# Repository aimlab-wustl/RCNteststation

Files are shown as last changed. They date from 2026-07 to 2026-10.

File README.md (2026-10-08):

# Automated Analog and Neuromorphic Integrated Circuits Test-Station

Characterizing a fabricated analog or neuromorphic IC often requires several instruments, separate software interfaces, and repeated manual setup for each device. This makes measurements slow to run and difficult to reproduce. The test station brings programmable biasing, precision voltage and current measurement, fast transient capture, and Python control into one modular system so that researchers can reuse the hardware and compare results across devices.

This project is supported in part by a Research Coordination Network (RCN) grant from the National Science Foundation (NSF), grant no. **2332166**.

[System documentation](https://aimlab-wustl.github.io/RCNteststation/) · [Hardware setup](https://aimlab-wustl.github.io/RCNteststation/docs/getting-started/hardware-setup) · [Software setup](https://aimlab-wustl.github.io/RCNteststation/docs/getting-started/software-setup)

## Test station system

| Subsystem | V3 implementation |
| --- | --- |
| Programmable bias | Five DAC80508 devices provide 40 independent 16-bit outputs over 0–5 V. A jumper selects NI USB-6212 or STM32H743 control. |
| Precision voltage acquisition | Two ADS131A04 devices provide eight differential 24-bit inputs. The current DMA implementation streams four channels from one chip at a time, up to 62.5 kSPS per channel. |
| Current measurement | Two OPA3S328 transimpedance circuits provide selectable nominal feedback from 2 kΩ to 2 MΩ, with their outputs measured by the precision ADC. |
| Fast transient capture | The STM32H743 internal ADC captures up to 8,000 samples at up to 3.2 MSPS on PA1 using timer-triggered DMA. |
| DUT connection | A ZIF40 daughterboard and package-specific adapter route bias, measurement, digital I/O, and timing signals to the device under test. |

## Firmware and Python control

STM32 firmware handles USB CDC communication, DAC control, ADS131A04 acquisition, TIA range selection, and transient capture. The NI USB-6212 provides a second control path and bench analog I/O. Python modules in [`python/hardware/`](python/hardware/) expose these functions to measurement scripts, which save data and generate plots for repeatable tests.

The [DAC characterization](https://aimlab-wustl.github.io/RCNteststation/docs/subsystems/dac/characterization) and [ADC characterization](https://aimlab-wustl.github.io/RCNteststation/docs/subsystems/adc/characterization) pages report measured board-level performance together with the conditions and limitations of each test.

The [Adaptive AC analysis](https://aimlab-wustl.github.io/RCNteststation/docs/automation/adaptive-ac) page demonstrates an Ax-based Bayesian optimization workflow that adaptively selects frequency points to estimate gain, phase, and −3 dB bandwidth with fewer physical measurements.

## Repository contents

| Path | Contents |
| --- | --- |
| [`pcb/`](pcb/) | V3 motherboard schematic and PCB, daughterboard PCB, and fabrication packages |
| [`firmware/`](firmware/) | STM32 firmware and required vendor libraries |
| [`python/`](python/) | Hardware drivers and measurement scripts |
| [`website/test-station/`](website/test-station/) | System documentation, schematics, and characterization figures |

## Status

MOSFET and op-amp DC measurements, fast step-response capture, and adaptive AC characterization have been implemented. The adaptive AC pipeline has been experimentally demonstrated using Gaussian-process-based Bayesian optimization to select measurement frequencies efficiently.

Noise characterization, adaptive PSRR testing, and the broader automated test-planning layer remain under development. The system is intended to support different post-tapeout devices through interchangeable DUT adapters and reusable measurement routines.

## Credit and license

Project development: **Kaiyuan (Sam) Kang**, AIMLAB, Washington University in St. Louis.

Unless otherwise noted, original project material is licensed under the [Creative Commons Attribution-NonCommercial 4.0 International Public License](LICENSE) (**CC BY-NC 4.0**). Noncommercial reuse and adaptation require attribution, a link to the license, and an indication of changes. Commercial use requires separate permission from the rights holder. Third-party STM32 libraries retain their own licenses in their respective directories.

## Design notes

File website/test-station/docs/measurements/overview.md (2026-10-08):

---
id: measurements-overview
title: Measurements Overview
sidebar_position: 1
---

# Measurements Overview

## Overview

The test station provides automated measurement pipelines for characterizing analog ICs.
Each pipeline runs from Python, saves timestamped outputs, and is designed to be reused
across different DUTs by changing a small set of parameters at instantiation.

Depending on the pipeline, measurements combine the DAC80508 and NI USB-6212
for bias generation and low-speed acquisition, the ADS131A04 for precision
voltage acquisition, the OPA3S328 TIA for current measurement, and the STM32
internal ADC for transient capture.

## Available Pipelines

| Pipeline | Script | Extracts | Status |
|---|---|---|---|
| [MOSFET -- Transfer curve](./mosfet/mosfet-overview#test-1----transfer-curve-id-vs-vgs) | `MosTest12.py` | Vth, peak gm, max Id | Implemented |
| [MOSFET -- Output characteristics](./mosfet/mosfet-overview#test-2----output-characteristics-id-vs-vds) | `MosTest12.py` | Id-Vds family, Id_sat, RDS(on) | Implemented |
| [MOSFET -- Body diode](./mosfet/mosfet-overview#test-3----body-diode-vsd-vs-is) | `MosTest3.py` | Vf, ideality factor n | Implemented |
| [Op-Amp -- DC](./opamp/opamp-overview#dc-characterization-opa_dcpy----dctest) | `OPA_DC.py` | Gain, Vos, INL, output swing, noise floor | Implemented |
| [Op-Amp -- CMR](./opamp/opamp-overview#common-mode-range-opa_cmrpy----cmrtest) | `OPA_cmr.py` | Common-mode input range | Implemented |
| [Op-Amp -- DC PSRR](./opamp/opamp-overview#dc-psrr-opa_psrrpy----psrrtest) | `OPA_psrr.py` | DC power supply rejection | Implemented |
| [Op-Amp -- Input bias current](./opamp/opamp-overview#input-bias-current-opa_ibpy----ibtest) | `OPA_Ib.py` | Ib+, Ib-, Ios | Implemented |
| [Op-Amp -- Step response](./opamp/opamp-overview#step-response-steptestpy) | `steptest.py` | Slew rate, rise time, overshoot | Implemented |
| [Op-Amp -- Adaptive AC Bode](../automation/adaptive-ac.md) | — | Gain + phase vs frequency, bandwidth | Implemented |
| Op-Amp -- Noise PSD | — | Input-referred noise spectral density | In progress |

## Output Files

Outputs are saved next to the script, prefixed with the `tag` parameter.

**MOSFET pipeline** -- three files per test run, timestamped:

| File | Contents |
|---|---|
| `test1_raw_*.csv` | Vgs, Vds, Id per sweep point |
| `test1_summary_*.json` | Vth, gm, pass/fail |
| `test1_final_*.png` | Transfer curve (linear + log) |
| `test2_raw_*.csv` | Id-Vds per Vgs curve |
| `test2_summary_*.json` | Id_sat, RDS(on) per Vgs |
| `test2_final_*.png` | Output curves + knee zoom + bar chart |
| `test3_raw_*.csv` | Vsd, Is per sweep point |
| `test3_summary_*.json` | Vf, ideality n, pass/fail |
| `test3_final_*.png` | Body diode (linear + log + fit) |

**Op-amp pipeline** -- per test:

| File | Contents |
|---|---|
| `dc_{tag}.json` | Baseline, coarse, fine sweep results |
| `dc_{tag}_fine.csv` | Vin, Aout, std, residual (fine sweep) |
| `dc_{tag}.png` | Coarse sweep + INL residual plot |
| `cmr_{tag}.json` | CMR sweep results |
| `cmr_{tag}.csv` | Vin, Aout, error per point |
| `cmr_{tag}.png` | Unity-gain sweep + error plot |
| `psrr_dc_{tag}.json` | PSRR sweep results |
| `psrr_dc_{tag}.csv` | V+, Aout, input-referred error |
| `psrr_dc_{tag}.png` | PSRR vs V+ plot |
| `ib_{tag}.json` | Ib+, Ib-, Ios in pA |
| `{tag}_step_response.npz` | Raw ADC samples + time axis |
| `{tag}_step_response.mat` | Same in MATLAB format |
| `{tag}_step_response_metrics.json` | Slew rate, rise time, overshoot, settling |
| `{tag}_step_response.png` | Full capture + zoomed plot |

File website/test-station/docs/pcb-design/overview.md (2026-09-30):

---
id: pcb-overview
title: PCB Overview
sidebar_position: 1
---

# PCB Overview

## Board Summary

| Parameter | Value |
|---|---|
| Current design revision | V3 |
| Architecture | Motherboard and daughterboard |
| DUT interface | Four ZIF40 board-to-board connections |
| EDA tool | Altium Designer |
| Power input | 9 V DC from a bench supply or external adapter |
| Main controllers | NI USB-6212 and STM32H743 |
| Precision outputs | 40-channel, 16-bit DAC subsystem |
| Precision inputs | Eight-channel, 24-bit ADC subsystem |

## System Block Diagram

Test station signal paths and control architecture

The test station supports both NI USB-6212 and STM32 control paths. A
jumper selects which controller drives the DAC daisy chain; the remaining
subsystems retain their dedicated control and acquisition paths. The NI USB-6212
supports analog I/O, general digital I/O, and PFI timing, while the STM32H743
provides USB CDC control, precision ADC acquisition, DAC control, TIA range
selection, and fast transient capture.

The ADS131A04 subsystem provides eight differential channels in total.
The current continuous DMA implementation streams four simultaneous channels
from one ADC at a time.

## V3 Motherboard

### 3D Rendering

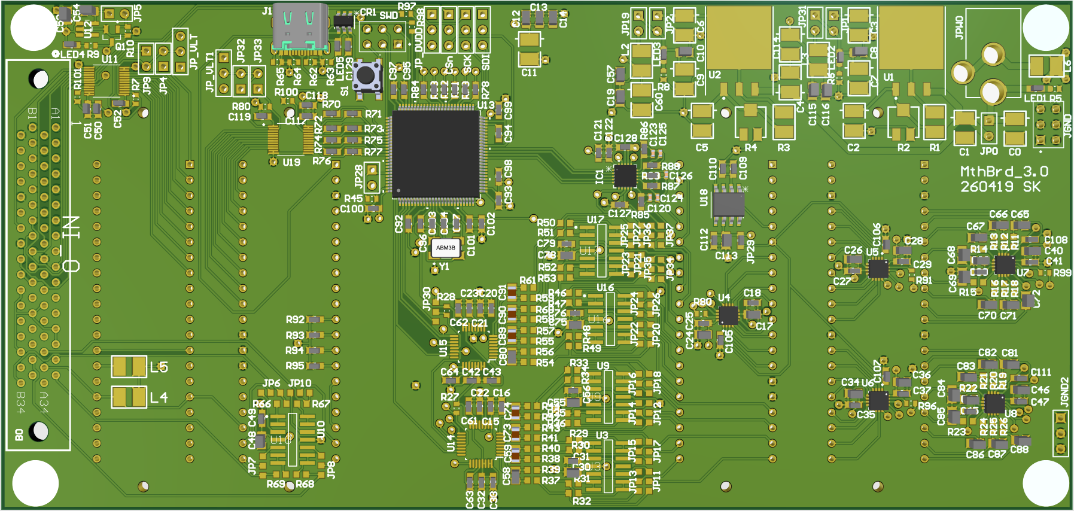
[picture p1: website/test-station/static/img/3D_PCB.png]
V3 motherboard 3D rendering


The V3 motherboard integrates the STM32 controller, precision DAC and ADC
subsystems, selectable TIA ranges, power regulation, and interfaces for the
NI USB-6212 and daughterboard.

### PCB Layout

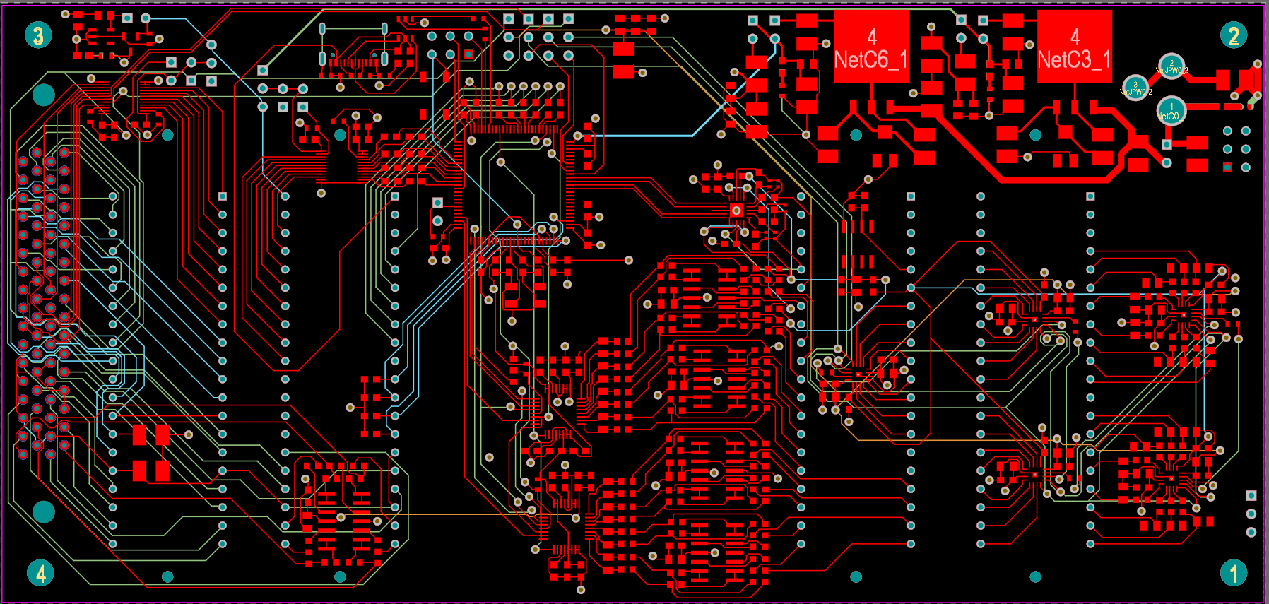
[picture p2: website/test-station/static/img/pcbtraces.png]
V3 motherboard PCB layout


The six-layer motherboard routes precision analog signals, digital control
lines, power rails, and the four daughterboard connections.

## V3 Daughterboard

### 3D Rendering

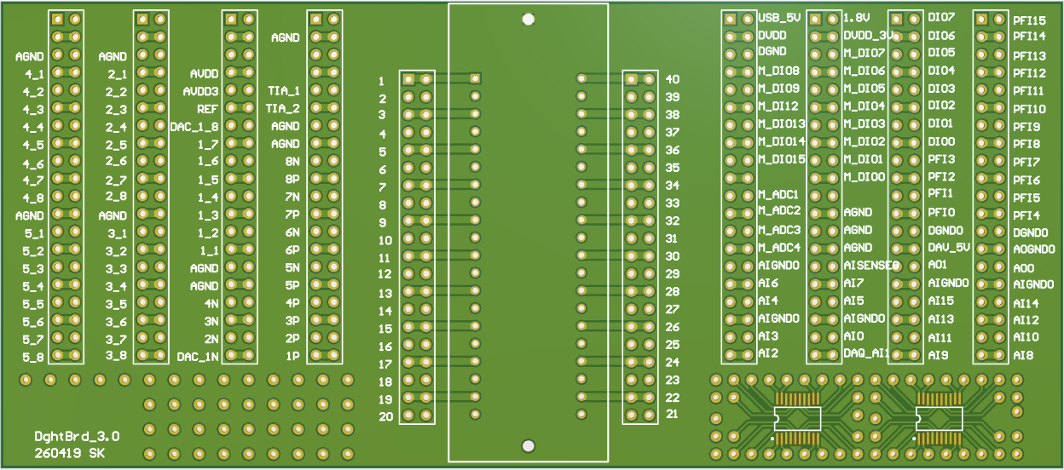
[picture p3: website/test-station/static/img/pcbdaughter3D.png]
V3 daughterboard 3D rendering


The V3 daughterboard connects the motherboard measurement resources to the
central 40-pin DUT socket. It routes DAC outputs, precision ADC inputs, TIA
connections, power and reference rails, general digital I/O, and PFI timing
signals to the DUT.

### PCB Layout

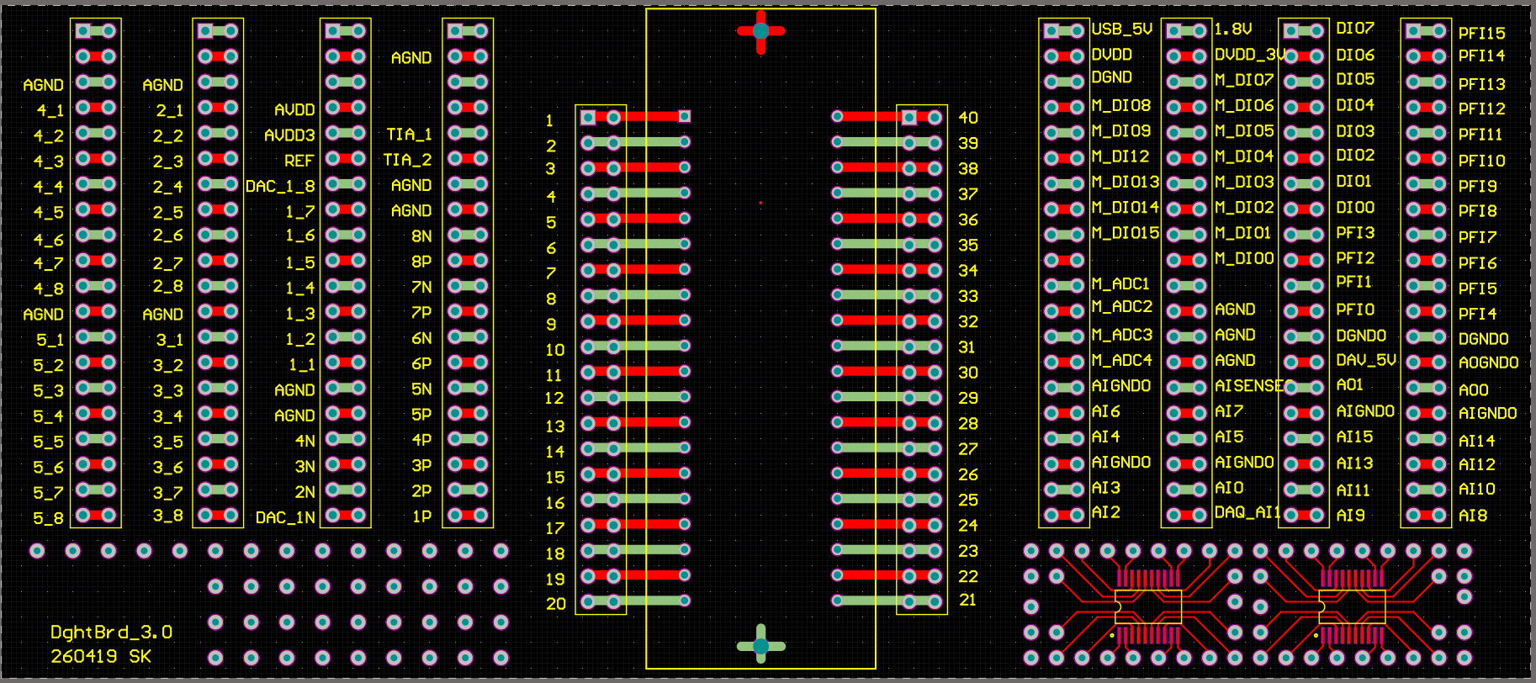
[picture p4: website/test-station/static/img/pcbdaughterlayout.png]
V3 daughterboard PCB layout


The daughterboard organizes the analog, digital, timing, and power connections
from the motherboard and routes them to the DUT socket.

## Main Interfaces

| Interface | Function |
|---|---|
| Four ZIF40 connectors | Motherboard-to-daughterboard connection |
| NI DAQ edge connector | NI USB-6212 analog, digital, and PFI signals |
| STM32 USB connector | USB CDC communication with the host PC |
| SWD header | STM32 firmware programming and debugging |
| 9 V input | Main board power input |

## Current Revision

All Altium source files and fabrication packages currently included in the
repository correspond to **V3**. Earlier board versions used different DAC
devices and are described in the [DAC documentation](../subsystems/dac), but
their PCB source files are not included in the current release.

See [Design Files](./pcb-files) for the Altium sources and fabrication packages.

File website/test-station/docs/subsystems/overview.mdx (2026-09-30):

---
id: subsystems-overview
title: System Overview
sidebar_position: 1
---

# System Overview

## Overview

The test station is built around two parallel control paths -- NI USB-6212 DAQ
and STM32H743 MCU -- that share the same DAC bias generation hardware, selectable
by jumper. All signals to and from the DUT route through a ZIF40 connector chain
on the motherboard into a daughterboard then to a package-specific DUT adapter.

## Block Diagram

Test station signal paths and control architecture

The two control paths (NI USB-6212 and STM32H743) connect to the host PC over USB.
Both can drive the DAC80508 daisy chain for bias voltage generation, selected by a jumper. The STM32 exclusively controls the ADS131A04 ADC via SPI2 DMA for
voltage measurement, and the OPA3S328 TIA gain selection via GPIO for current
measurement. The TIA output feeds back into the ADS131 so current readings are
digitized directly by the ADC. DIO lines from both controllers pass through
SN74LVC8T245 level translators before reaching the ZIF40 DUT interface -- output
voltage (1.8V, 3.3V, or 5V) and direction are both set by shunt jumpers on the board.

## Subsystem Summary

| Subsystem | Key Component | Channels | Interface | Performance |
|---|---|---|---|---|
| [Power](./power) | LM1086, TPS7A2018, ADR4525CRZ | 4 rails + 2.5V ref | -- | -- |
| [NI DAQ](./ni-daq) | NI USB-6212 | 16 AI, 2 AO, 32 DIO, 16 PFI | USB | AI: 400 kS/s |
| [STM32](./stm32) | STM32H743VIT6 | 18 DIO, 4 ADC | USB CDC | Burst ADC: 3.2 MSPS |
| [DAC](./dac) | DAC80508 x5 | 40 ch, 16-bit, 0-5V | SPI bit-bang | +/-1 LSB INL |
| [ADC](./adc) | ADS131A04 x2 | 8 ch diff, 24-bit, 0-4V | SPI2 DMA | 62.5 kSPS, live stream |
| [TIA](./tia) | OPA3S328 (1 chip, 2 circuits) | 2 ch | GPIO | +/-1 uA to +/-1.2 mA |

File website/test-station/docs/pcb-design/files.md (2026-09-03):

---
id: pcb-files
title: Design Files
sidebar_position: 3
---

# PCB Design Files

## Available Files

The repository contains the editable Altium Designer source files and the
V3 fabrication packages for both boards.

| Resource | Location | Description |
|---|---|---|
| V3 Altium project | [`pcb/altium/AIMLAB_TESTSTATION_V3`](https://github.com/aimlab-wustl/RCNteststation/tree/main/pcb/altium/AIMLAB_TESTSTATION_V3) | Motherboard and daughterboard schematics, PCB layouts, project files, and output jobs |
| Motherboard V3 Gerbers | [`MotherBoardGerber.zip`](https://github.com/aimlab-wustl/RCNteststation/blob/main/pcb/fabrication/MotherBoardGerber.zip) | Motherboard Gerber and drill files |
| Daughterboard V3 Gerbers | [`DaughterBoardGerber.zip`](https://github.com/aimlab-wustl/RCNteststation/blob/main/pcb/fabrication/DaughterBoardGerber.zip) | Daughterboard Gerber and drill files |

## Repository Structure

```text
pcb/
├── altium/
│   └── AIMLAB_TESTSTATION_V3/
│       ├── Altium project files
│       ├── Motherboard schematic and PCB layout
│       ├── Daughterboard schematic and PCB layout
│       ├── Job-Mother.OutJob
│       └── Job-Daughter.OutJob
└── fabrication/
    ├── MotherBoardGerber.zip
    └── DaughterBoardGerber.zip
```

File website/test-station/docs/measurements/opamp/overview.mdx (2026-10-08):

---
id: opamp-overview
title: Op-Amp Measurements
sidebar_position: 1
---

# Op-Amp Measurements

## Overview

The test station supports automated op-amp DC characterization through a pipeline of
independent test scripts, each targeting a specific parameter set. Tests share the same
physical fixture where possible and are designed to be reused across any op-amp DUT by
changing the tag and channel assignments at instantiation. The pipeline was validated on
the **OPA4388IDR** (TI, precision zero-drift RRIO, used as the AI input buffer on
the motherboard) in a gain-11 non-inverting configuration.

The pipeline covers: DC gain, Vos, INL, output swing, CMR, DC PSRR, input bias current,
and step response.

## Setup

The gain-11 fixture is shared by DC, PSRR, Ib, and step response tests.
CMR requires a rewire to unity gain (remove Rf and Rg, short A- to Aout directly).

```
V+   --> 5.0V supply (100nF + 10uF decoupling at pin)
V-   --> AGND

DAC80508 (NI path) ----------------------> A+

ADR4525CRZ 2.5V --[Rg 10k]--> A- <--[Rf 100k]--> Aout
ADR4525CRZ 2.5V ------------> ADS131 AINN

Aout --> ADS131 AINP
ADC reads (Aout - Vref) differentially; software adds Vref back

Gain = 1 + Rf/Rg = 11 (nominal)
```

This is a hybrid fixture: DAC on the NI USB-6212 path, ADC on the STM32/ADS131 path,
running simultaneously. Bring V+ up before commanding any DAC voltage above 0V, and
zero the DAC before removing V+.

---

## DC Characterization (`OPA_DC.py` -- `DCTest`)

**Script:** `measurements/dc.py` -- `DCTest` class

Three sequential steps: baseline noise floor, coarse sweep (operating range), fine sweep
(precise gain, Vos, INL). The coarse sweep auto-determines the linear input range, which
the fine sweep uses directly -- no manual range setting needed.

```python
from measurements.dc import DCTest
dc = DCTest(dac_num=1, dac_ch=1, adc_chip=1, adc_ch=1, tag="opa4388")
dc.run_all()
```

**Key parameters:**
```python
vref   = 2.5    # reference node voltage (V)
vpos   = 5.0    # positive supply (V)
g_nom  = 11.0   # nominal gain (1 + Rf/Rg)
settle_s = 0.005  # settle time per DAC step (s)
n_avg    = 64     # frames averaged per point
```

**OPA4388 results vs datasheet:**

| Parameter | Datasheet spec | Measured | Notes |
|---|---|---|---|
| Gain | 11.000 (nominal) | **10.865** | -1.3% -- within 1% resistor tolerance |
| Vos (fixture) | 0.25 uV typ (chip) | **-1957 uV** | Fixture/resistor limited, not chip Vos |
| INL | -- | **0.113%** | Asymmetric, steeper near +rail (real RRIO compression) |
| INL max | -- | **4342 uV out** | Referred to output |
| Baseline noise | -- | **235 uVrms** | Output node, ADS131 at default OSR |
| Output swing low | 0V (RRIO) | ~0.05V | Rail limit |
| Output swing high | 5V (RRIO) | ~5.0V | Rail limit |

The Vos measurement reflects the fixture's resistor mismatch, not the chip's true
offset (0.25 uV typ, far below what this rig can resolve at gain 11 with 1% resistors).

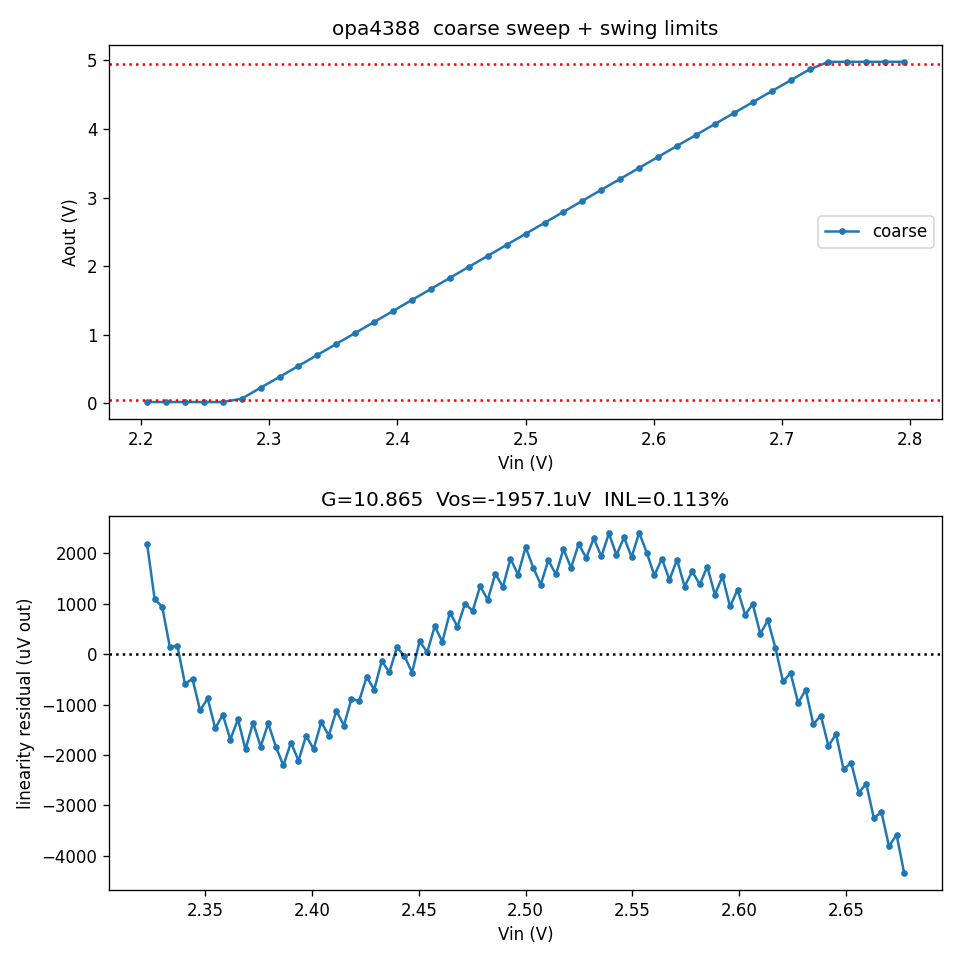
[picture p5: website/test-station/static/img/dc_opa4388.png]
OPA4388 DC sweep


---

## Common-Mode Range (`OPA_cmr.py` -- `CMRTest`)

**Script:** `measurements/cmr.py` -- `CMRTest` class

**Rewire required:** remove Rf and Rg, tie A- directly to Aout (unity gain buffer).
Sweeps A+ from 0 to Vpos, measures error = Aout - Vin.

```python
from measurements.cmr import CMRTest
cmr = CMRTest(dac_num=1, dac_ch=1, adc_chip=1, adc_ch=1, tag="opa4388")
cmr.run_all()
```

**OPA4388 results vs datasheet:**

| Parameter | Datasheet spec | Measured | Notes |
|---|---|---|---|
| CMR range | 0 to V+ (RRIO input) | **0.05 to 5.0V** | 50mV error threshold |
| Error within range (mean) | -- | **-422 uV** | Offset from ADC/DAC mismatch |
| Error within range (RMS) | -- | **4451 uV** | Dominated by gain-1 noise floor |

The error at Vin near 0V (78 mV spike visible in plot) and near 5V (-26 mV drop) are
real rail proximity effects, not ADC clipping -- the error curves smoothly rather than
pinning flat at a constant value.

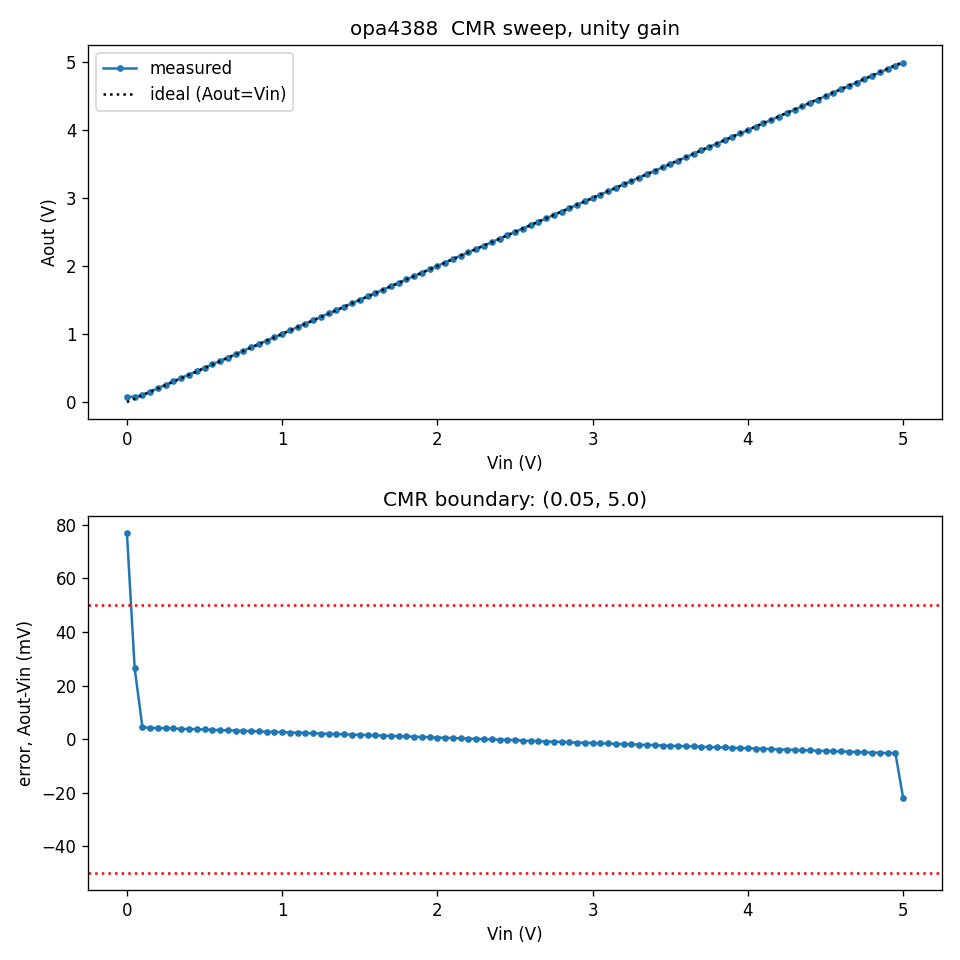
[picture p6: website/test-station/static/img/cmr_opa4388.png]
OPA4388 CMR sweep


---

## DC PSRR (`OPA_psrr.py` -- `PSRRTest`)

**Script:** `measurements/psrr_dc.py` -- `PSRRTest` class

Same gain-11 fixture as DC test. Sweeps V+ from 4.5V to 5.5V while holding the input
fixed, measures change in output referred back to input.

```python
from measurements.psrr_dc import PSRRTest
psrr = PSRRTest(dac_num=1, dac_ch=1, adc_chip=1, adc_ch=1, tag="opa4388")
psrr.run_all()
```

**OPA4388 results vs datasheet:**

| Parameter | Datasheet spec | Measured | Notes |
|---|---|---|---|
| DC PSRR | 130 dB typ | **86.1 dB** | Input-referred, gain=10.86 |
| V+ sweep range | -- | 4.5 to 5.5V | 1V total variation |

The measured 86.1 dB is lower than the datasheet typical (130 dB) primarily because
the measurement is limited by the DAC80508 reference stability and ADS131 noise floor
rather than the amplifier itself. The result is a lower bound on the true PSRR.

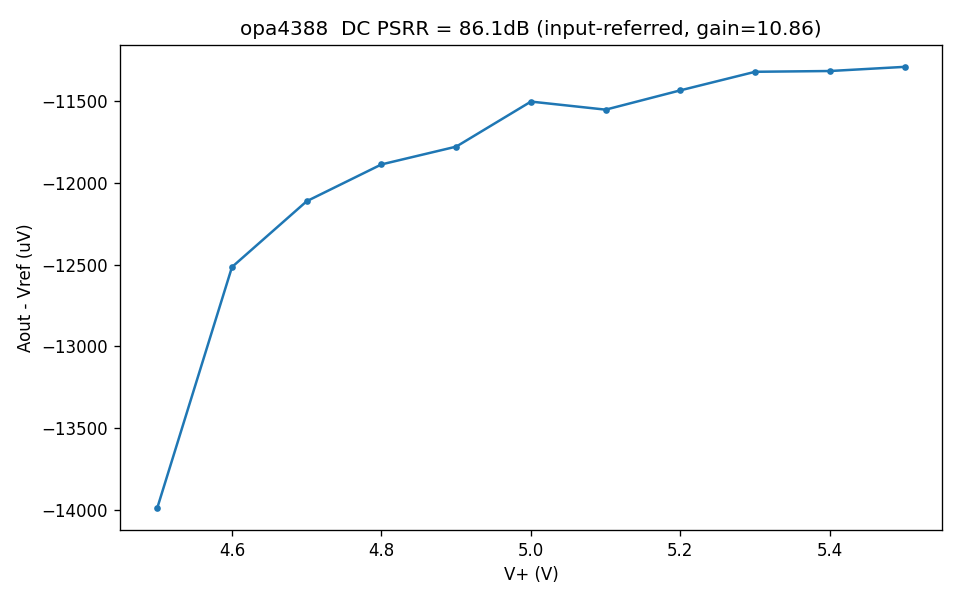
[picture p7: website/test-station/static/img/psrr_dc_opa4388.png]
OPA4388 DC PSRR


---

## Input Bias Current (`OPA_Ib.py` -- `IbTest`)

**Script:** `measurements/ib.py` -- `IbTest` class

Uses the TIA (OPA3S328, B_2M range, Rf=1.87 MOhm calibrated) to measure the op-amp's
input bias current at the non-inverting (A+) and inverting (A-) inputs. The fixture
disconnects Rg/Rf from A- to isolate the input current path.

```python
from measurements.ib import IbTest
ib = IbTest(tag="opa4388")
ib.run_all()
```

**OPA4388 results vs datasheet:**

| Parameter | Datasheet spec | Measured | Notes |
|---|---|---|---|
| Ib+ | 1 pA typ (zero-drift) | **12,755 pA** | TIA noise floor limited |
| Ib- | 1 pA typ (zero-drift) | **12,766 pA** | TIA noise floor limited |
| Ios (Ib+ - Ib-) | -- | **-11 pA** | Well within TIA noise -- meaningful |
| TIA range used | -- | B_2M (1.87 MOhm) | Noise floor ~5 nA |

The absolute Ib values (~12.8 nA) are dominated by the TIA's ~12 nA instrumentation
offset artifact (documented in the TIA section). The offset is consistent and matches
the known TIA floor. However, the offset difference Ios = Ib+ - Ib- = -11 pA is
meaningful -- the common-mode offset cancels, leaving the true differential bias
current visible below the noise floor.

---

## Step Response (`steptest.py`)

**Script:** `measurements/steptest.py`

Step response uses STM32 GPIO PD9 to generate the input step and the STM32 internal ADC
(PA1) at 3.2 MSPS via TIM1/TRGO2 and DMA burst capture to record the output. The
OPA4388 Aout connects to PA1 through a 10k/10k resistor divider (0.5x scaling) to keep
the output swing within PA1's 3.3V range. 8000 samples are captured per run with 1600
pre-trigger samples (20%), giving a -500 us to +2000 us window around the step edge.

**Test fixture:**
```
STM32 PD9 --> [1k/50 Ohm divider (optional)] --> OPA4388 A+
OPA4388 Aout --> [10k/10k divider, 0.5x] --> PA1
Gain-11 feedback unchanged (Rf=100k, Rg=10k, Vref=2.5V)
```

Two captures were taken on the OPA4388 at gain 11:

**Capture 1 -- full 3.3V GPIO step on A+:**

| Parameter | Value |
|---|---|
| Output step size | ~208 mV (reconstructed after divider) |
| Slew rate | 0.98 V/us |
| Rise time | under 0.31 us (one sample at 3.2 MSPS -- upper bound) |
| Overshoot | 112% |
| Settling (2%) | beyond 2ms capture window |

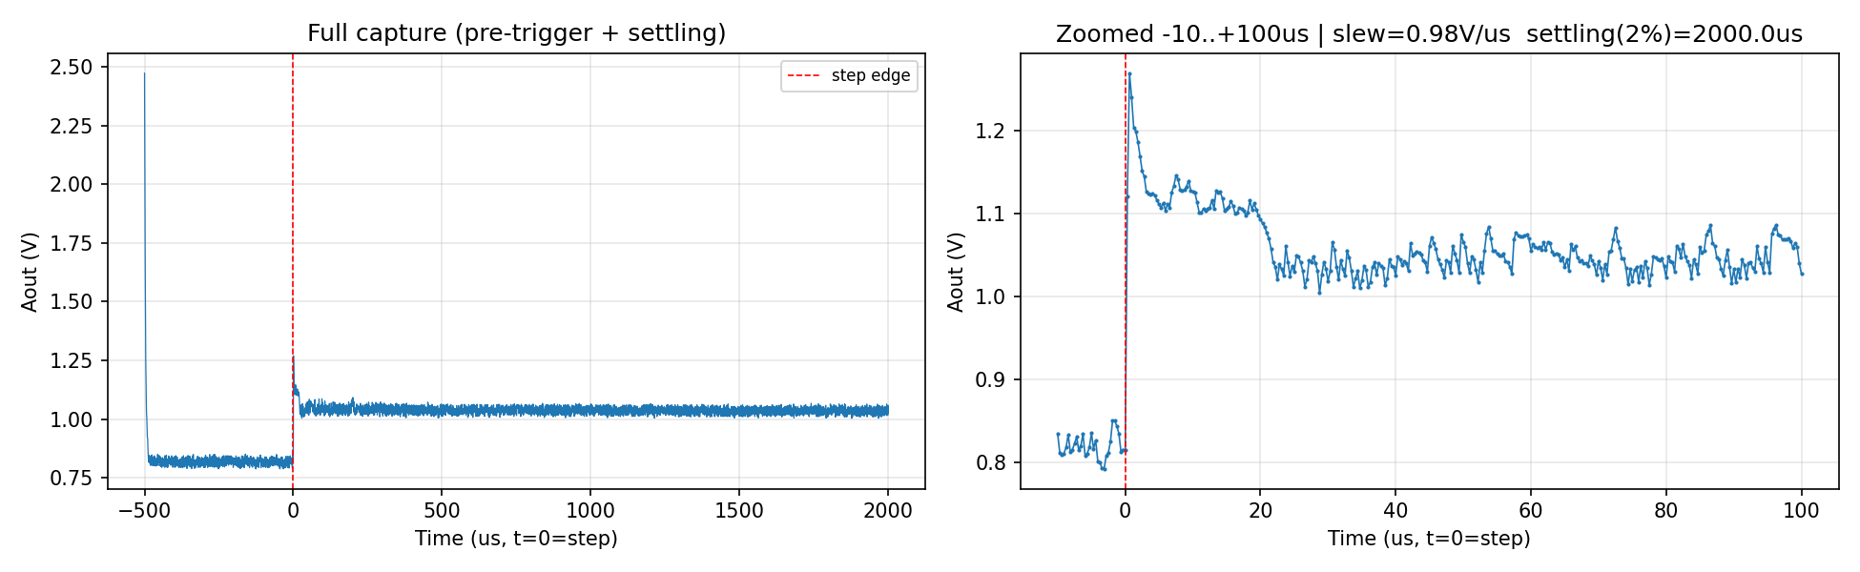
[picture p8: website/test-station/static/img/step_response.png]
OPA4388 full step response


**Capture 2 -- attenuated step via 1k/50 Ohm divider on A+:**

| Parameter | Value |
|---|---|
| Output step size | ~39 mV |
| Slew rate | 0.53 V/us |
| Rise time | 13.4 us |
| Overshoot | 80% |
| Settling (2%) | not within 100 us window |

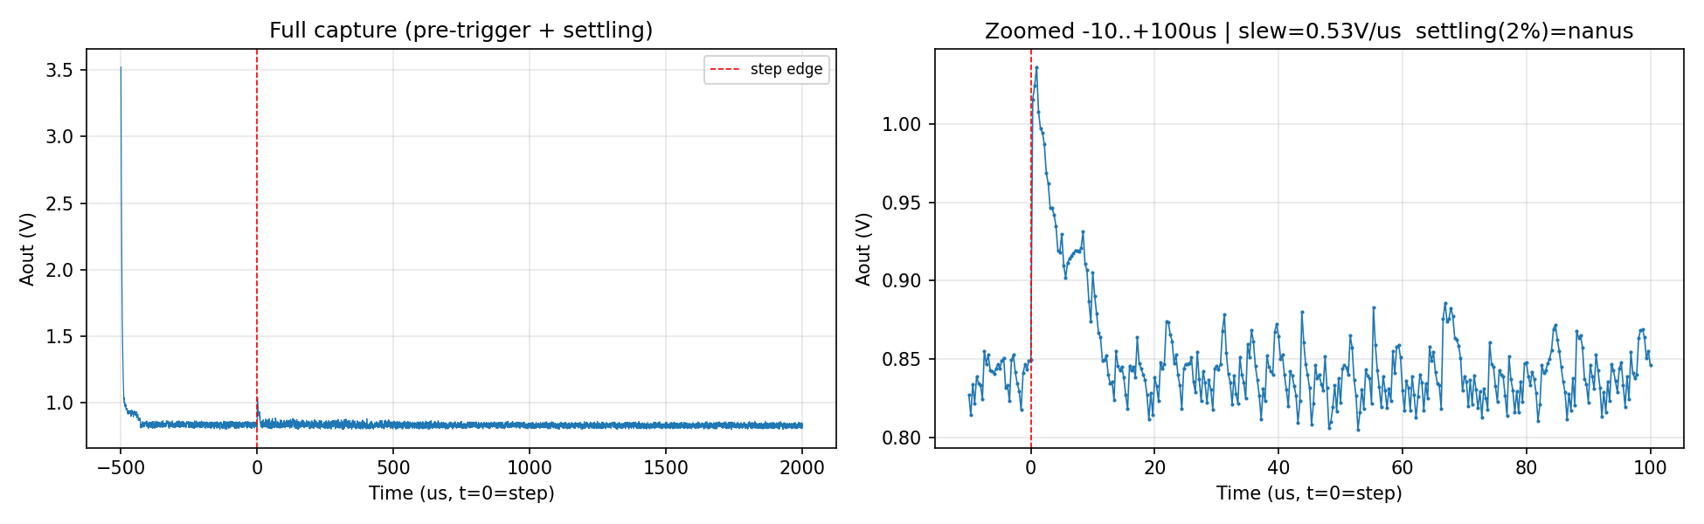
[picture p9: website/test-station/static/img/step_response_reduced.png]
OPA4388 reduced step response


Both captures confirm the step response capture pipeline is working at 3.2 MSPS with
a clean pre-trigger baseline and correct Aout reconstruction via the 10k/10k divider.
The large overshoot and slow settling reflect the op-amp operating well outside its
linear small-signal region. Small-signal frequency response is characterized separately
using the adaptive AC pipeline; see [Adaptive AC Analysis](../../automation/adaptive-ac.md).

---

## Output Files

Each test saves:

| File | Contents |
|---|---|
| `dc_{tag}.json` | Baseline, coarse, fine sweep results |
| `dc_{tag}_fine.csv` | Vin, Aout, std, residual per fine point |
| `dc_{tag}.png` | Coarse sweep + INL residual plot |
| `cmr_{tag}.json` | CMR sweep results |
| `cmr_{tag}.csv` | Vin, Aout, error per point |
| `cmr_{tag}.png` | Unity-gain sweep + error plot |
| `psrr_dc_{tag}.json` | PSRR sweep results |
| `psrr_dc_{tag}.csv` | V+, Aout, input-referred error per point |
| `psrr_dc_{tag}.png` | PSRR vs V+ plot |
| `ib_{tag}.json` | Ib+, Ib-, Ios in pA |

## Extending to Other Devices

Change the `tag` and channel assignments at instantiation. For a different gain, update
`g_nom` and the physical Rf/Rg values:

```python
dc = DCTest(dac_num=1, dac_ch=2, adc_chip=1, adc_ch=2,
            g_nom=21.0,   # e.g. Rf=200k, Rg=10k
            tag="lmv321")
dc.run_all()
```

## Planned Additions

- Input noise PSD (FFT of ADS131 DMA capture)
- AC PSRR and CMRR vs frequency
- Output short-circuit current measurement

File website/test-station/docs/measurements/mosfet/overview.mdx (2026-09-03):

---
id: mosfet-overview
title: MOSFET Measurements
sidebar_position: 1
---

# MOSFET Measurements

## Overview

The test station supports automated MOSFET DC characterization through a
three-test pipeline built on the NI USB-6212 and DAC80508. The pipeline extracts
threshold voltage, transconductance, output characteristics, and body diode parameters
with no manual bias point configuration -- Test 1 automatically passes the extracted
Vth to Test 2 to set appropriate Vgs steps. All tests save timestamped CSV, JSON
summary, and PNG plot outputs next to the script.

The pipeline was validated on the **SI2302CDS** (Vishay, 20V TrenchFET, SOT-23)
and is designed to be reusable for other N-channel MOSFETs within the station's voltage and current limits by adjusting the sweep ranges and
resistor values at the top of each script.

## Setup

The same fixture is used for Test 1 and Test 2 with no rewiring between them.

```
NI AO ch1 --[10 kOhm R_drain]--> Drain (pin 3) --> AI ch0  (V_drain)
DAC1 CH2  ------------------->   Gate  (pin 1) --> AI ch2  (V_gate)
                                  Source (pin 2)--> AI ch1  (V_source)
                                               \--[100 Ohm R_shunt]--> GND
```

Measured quantities derived from the three voltages:
```
Id  = V_source / R_shunt
Vgs = V_gate - V_source
Vds = V_drain - V_source
```

Each point averages 64 samples at 10 kS/s for noise rejection. A 100 ms settle
delay is applied after each DAC voltage step.

## Configurable Parameters

At the top of each script:

```python
DEVICE      = "Dev1"       # NI DAQ device name
R_DRAIN     = 10_000.0     # measure with DMM and update
R_SHUNT     = 100.0        # measure with DMM and update
SETTLE      = 0.10         # seconds per bias point
N_AVG       = 64           # samples averaged per reading
```

Updating `R_DRAIN` and `R_SHUNT` with DMM-measured values removes the resistor
tolerance error from all extracted parameters.

---

## Test 1 -- Transfer Curve (Id vs Vgs)

**Script:** `MosTest12.py` -- `run_test1()`

Sweeps Vgs from 0 to 2.5 V in 101 steps while the drain-bias source is
set to 5 V through the 10 kΩ drain resistor. The actual Vds is calculated
from the measured drain and source voltages. Extracts threshold
voltage and peak transconductance automatically.

**Extractions:**
- **Vth** -- Vgs interpolated at Id = VTH_ID (constant current method)
- **Peak gm** -- max(dId/dVgs) via numpy gradient

**SI2302CDS results vs datasheet:**

| Parameter | Datasheet spec | Measured | Notes |
|---|---|---|---|
| VGS(th) | 0.40-0.85V (Id=250 uA) | **665 mV** | PASS -- different Id threshold (50 uA) |
| Peak gm | 13 S typ (Id=3.6A) | **1.098 mS** | Low-Id regime -- not comparable to spec |
| Max Id | -- | **95.9 uA** | R_drain limited (5V / 10kOhm) |

The gm spec in the datasheet is measured at full conduction (Id=3.6A) -- the pipeline
operates in the low-current regime so the values are not directly comparable. Both
are valid measurements of different operating points.

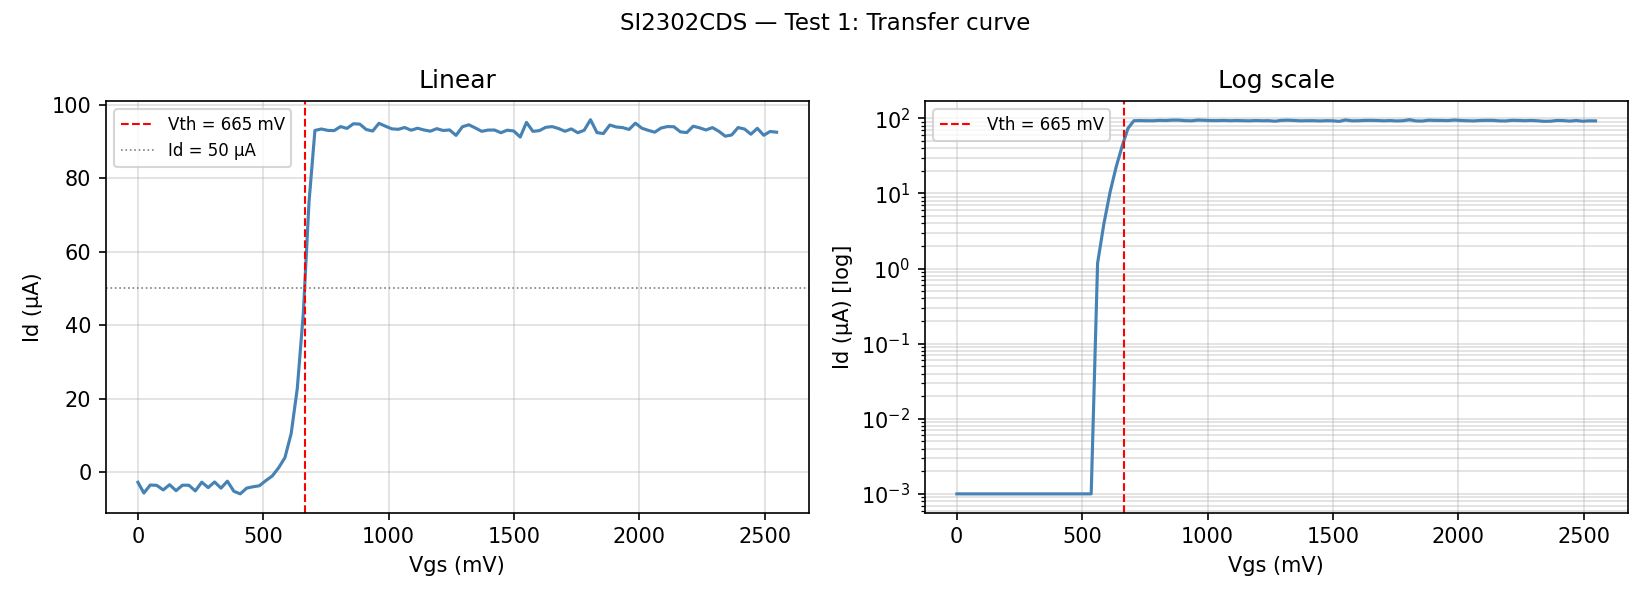
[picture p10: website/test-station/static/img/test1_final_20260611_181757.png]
Transfer curve


---

## Test 2 -- Output Characteristics (Id vs Vds)

**Script:** `MosTest12.py` -- `run_test2(vth)`

Sweeps Vds from 0 to 10V for multiple Vgs steps. Vgs bias points are set
automatically from the Vth extracted in Test 1 -- no manual configuration needed.

**Key parameters (adjustable in script):**
```python
V_DRAIN_MAX = 10.0    # max Vds sweep voltage (V)
# Vgs steps auto-generated: 0.7*Vth, Vth, 1.3*Vth, 1.7*Vth, 2.2*Vth, 2.9*Vth
```

**Extractions per Vgs curve:**
- **Id_sat** -- mean of final 10 Vds points (saturation current)
- **RDS(on)** -- extracted from linear region slope for all Vgs curves above Vth

**SI2302CDS measured output characteristics:**

| Vgs | Id_sat | RDS(on) | Notes |
|-----|---|---|---|
| 0.47V | off | -- | Below Vth |
| 0.67V | 72 uA | ~615 Ohm | Near Vth, R_drain dominated |
| 0.86V | 171 uA | -- | Saturated |
| 1.20V | 171 uA | -- | Saturated |
| 1.66V | 171 uA | -- | Saturated |
| 2.19V | 171 uA | -- | Saturated |

The approximately 171 µA plateau was repeatable across two runs. However,
because the measurement uses a 10 kΩ drain resistor, these results represent
the combined MOSFET-and-fixture load line rather than the device's intrinsic
high-current saturation characteristics. The reported resistance near
threshold should likewise be treated as an apparent low-current resistance,
not the datasheet RDS(on).

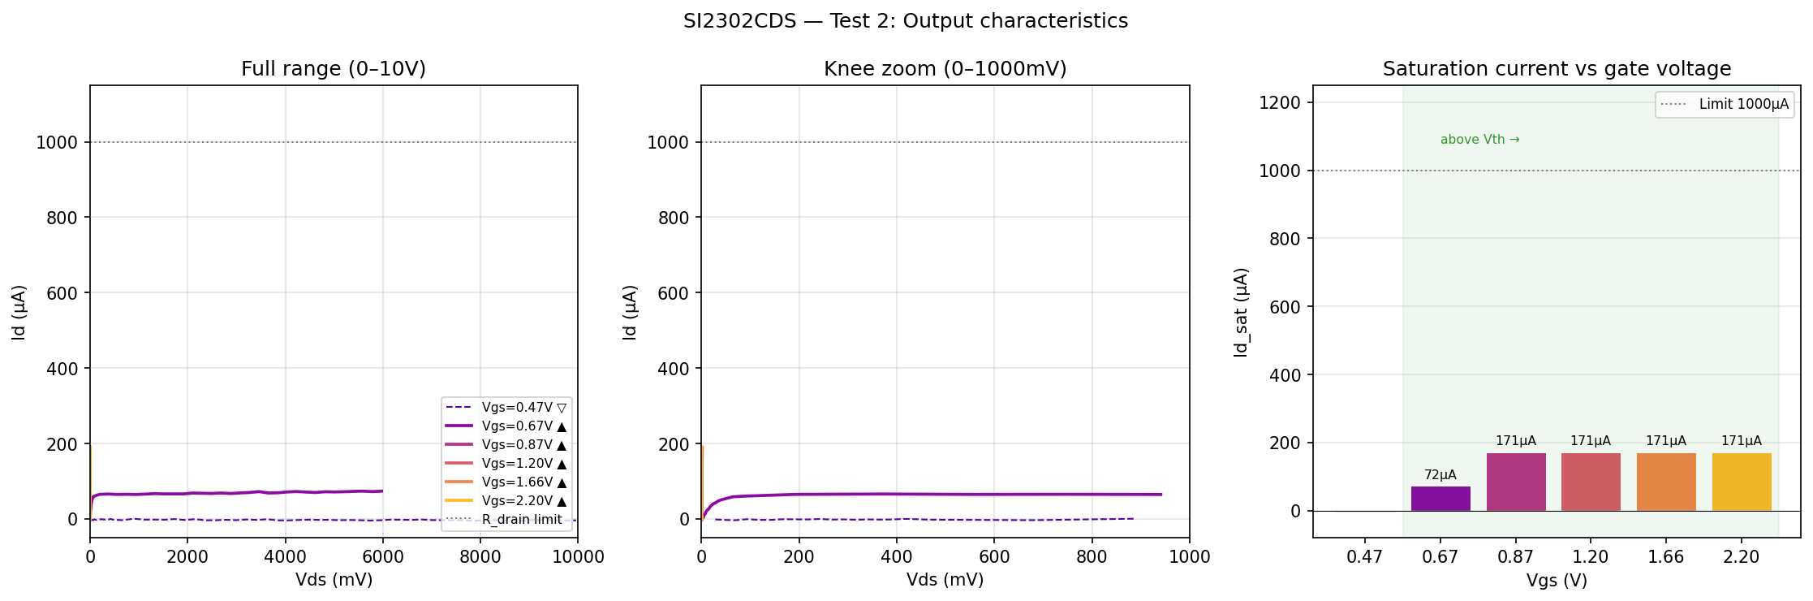
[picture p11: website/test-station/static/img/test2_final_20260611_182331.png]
Output characteristics


---

## Test 3 -- Body Diode (Vsd vs Is)

**Script:** `MosTest3.py`

Characterizes the intrinsic body diode by sweeping Source voltage with Gate and Drain
held at 0V (MOSFET fully off). Uses a 10 kOhm shunt to measure diode current.

**Key parameters:**
```python
VSD_START = 0.0
VSD_STOP  = 1.4      # stay well below breakdown
VSD_STEPS = 141
R_SHUNT   = 10_000   # 10 kOhm for Test 3 (different from Test 1/2)
IS_TH     = 50e-6    # threshold current for Vf extraction
```

**Extractions:**
- **Vf** -- Vsd interpolated at Is = IS_TH
- **Ideality factor n** -- linear fit of log(Is) vs Vsd in the 5-45 uA window

**SI2302CDS body diode results:**

| Parameter | Datasheet spec | Measured | Notes |
|---|---|---|---|
| VSD (Vf) | 0.7V typ, 1.2V max (Is=0.95A) | **500 mV** (Is=50 uA) | Well within spec at low current |
| Ideality n | 1-2 (ideal) | 8.15 | Artifact of 10 kOhm shunt -- see note |

The Vf measurement at 500 mV is reliable. The high ideality factor is a known
artifact: at low Is the 10 kOhm shunt voltage drop dominates the I-V curve and
distorts the exponential region used for the fit. The Vf extraction is unaffected.
A lower shunt value would improve the ideality fit at the cost of current resolution.

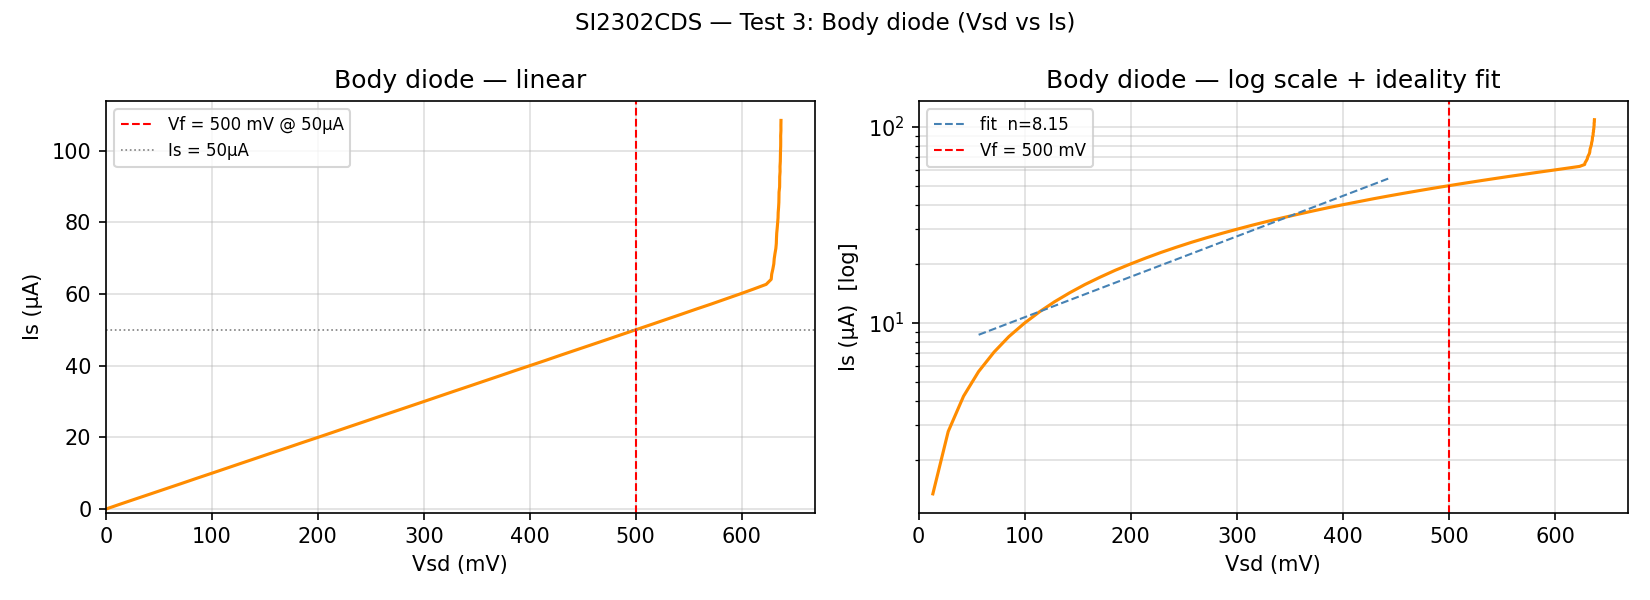
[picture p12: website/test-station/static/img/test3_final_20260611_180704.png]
Body diode


---

## Output Files

Each test run saves three timestamped files next to the script:

| File | Contents |
|---|---|
| `test1_raw_*.csv` | Vgs_cmd, V_drain, V_source, V_gate, Vgs, Vds, Id per point |
| `test1_summary_*.json` | Vth, gm, max_Id, pass/fail |
| `test1_final_*.png` | Linear + log scale transfer curve |
| `test2_raw_*.csv` | Vds, Id per point per Vgs curve |
| `test2_summary_*.json` | Id_sat, RDS(on) per Vgs, Vth used |
| `test2_final_*.png` | Output curves + knee zoom + Id_sat bar chart |
| `test3_raw_*.csv` | Vsd, Is per point |
| `test3_summary_*.json` | Vf, ideality n, pass/fail |
| `test3_final_*.png` | Linear + log scale with ideality fit |

## Running the Pipeline

```python
# Test 1 + 2 (no rewiring between them)
python MosTest12.py
# Runs Test 1, prints results, pauses for confirmation, then runs Test 2

# Test 3 (separate fixture -- rewire shunt to 10 kOhm first)
python MosTest3.py
```

## Extending to Other Devices

To characterize a different N-channel MOSFET, update in the script:

```python
# Adjust sweep ranges for your device's expected Vth
VGS_STOP  = 5.0      # extend if Vth > 2.5V
VTH_ID    = 250e-6   # match datasheet Vth test condition if known

# Adjust drain resistor for your expected Id range
R_DRAIN   = 1_000.0  # lower for higher Id devices
```

The Vth extracted in Test 1 automatically scales the Vgs bias points for Test 2.

## Planned Additions

- Subthreshold slope (SS = dVgs / d(log Id) in weak inversion)
- DIBL extraction (Vth shift between two Vds values)
- gm vs Vgs curve (full transconductance characteristic)
- Multi-device batch mode with statistical summary (mean, std, min, max across samples)
- P-channel MOSFET variant (MosTestP.py, negative bias sweeps)

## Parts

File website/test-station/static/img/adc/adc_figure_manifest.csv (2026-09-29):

dest_filename | source_path | dest_path | description | recommended_usage
adc_noise_vs_speed.png | C:\WashU\AIM\PerformanceAnalysis\ADC\analysis\03_presentation\figures\01_adc_noise_vs_speed.png | C:\WashU\AIM\RCNteststation\website\test-station\static\img\adc\adc_noise_vs_speed.png | Cross-system ADC comparison showing noise versus speed for ADS131A04, NI USB-6212, STM32 ADC, and DAQ6510 reference. | characterization.mdx (optional late-section cross-system context)
ads_osr_tradeoff.png | C:\WashU\AIM\PerformanceAnalysis\ADC\analysis\03_presentation\figures\06_ads_osr_tradeoff.png | C:\WashU\AIM\RCNteststation\website\test-station\static\img\adc\ads_osr_tradeoff.png | ADS131A04 OSR tradeoff plot showing measured shorted-input noise versus output sample rate, with TI typical values overlaid. | index.mdx and characterization.mdx
ads_datasheet_comparison.png | C:\WashU\AIM\PerformanceAnalysis\ADC\analysis\03_presentation\figures\04_ads_datasheet_comparison.png | C:\WashU\AIM\RCNteststation\website\test-station\static\img\adc\ads_datasheet_comparison.png | ADS131A04 measured shorted-input noise compared with datasheet-typical values across OSR. | characterization.mdx
ads_filter_comparison.png | C:\WashU\AIM\PerformanceAnalysis\ADC\analysis\03_presentation\figures\03_ads_filter_comparison.png | C:\WashU\AIM\RCNteststation\website\test-station\static\img\adc\ads_filter_comparison.png | Comparison of the two ADS input filter families (10 nF versus 1 nF) across tested rates. | characterization.mdx
ads_buffered_vs_unbuffered.png | C:\WashU\AIM\PerformanceAnalysis\ADC\analysis\03_presentation\figures\05_ads_buffered_vs_unbuffered.png | C:\WashU\AIM\RCNteststation\website\test-station\static\img\adc\ads_buffered_vs_unbuffered.png | Comparison of buffered and unbuffered ADS front-end paths, highlighting noise and DC-error behavior. | characterization.mdx

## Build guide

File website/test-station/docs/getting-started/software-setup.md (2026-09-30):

---
id: software-setup
title: Software Setup
sidebar_position: 2
---

# Software Setup

## 1. Firmware (STM32)

### Required Tools

- **STM32CubeIDE v2.1.1** -- IDE and compiler
- **STM32CubeMX** -- peripheral configuration
- **STM32CubeProgrammer** -- connection diagnostics and manual flash
- **STLINK-V3MINIE** -- SWD debugger

### Get the Firmware

The STM32 firmware is located in the repository:

[firmware/test_station_fw](https://github.com/aimlab-wustl/RCNteststation/tree/main/firmware/test_station_fw)

### Flashing Firmware

1. Open STM32CubeIDE.
2. Import the firmware project: `File --> Import --> Existing Projects`.
3. Connect STLINK to the SWD header. See [Hardware Setup](./hardware-setup#swd-programming-port).
4. Power the board.
5. Click **Run** or **Debug** to build and flash.
6. Verify that the STM32 appears as a USB CDC virtual COM port after flashing.

### Verifying USB CDC Enumeration

1. Open **Windows Device Manager**.
2. Expand **Ports (COM & LPT)**.
3. Find `STMicroelectronics Virtual COM Port`.
4. Note its assigned port number, such as `COM4` or `COM7`.
5. Enter that port number as `STM_COM_PORT` in `config.py`.

The expected USB identifiers are VID `0483` and PID `5740`. If the COM
port does not appear, check the USB cable, driver installation, and the
D+/D− connections on the board.
---

## 2. Python Environment

All Python control scripts run in the `test-station` conda environment.

The Python control scripts are located in the repository:

[python](https://github.com/aimlab-wustl/RCNteststation/tree/main/python)

### Quick Setup

From the repository root, create the environment and install the Python dependencies:

```bash
conda create -n test-station python=3.13
conda activate test-station
cd python
pip install -r requirements.txt
```

### Main Python Packages

```text
# DAQ and instrument control
nidaqmx          # NI USB-6212 control
pyvisa           # Keithley 2450 VISA interface
pyserial         # STM32 USB CDC communication

# Numerical and scientific computing
numpy
scipy
pandas

# Plotting
matplotlib

# Data storage
h5py             # HDF5 for large measurement datasets

# Utilities
tqdm             # Progress bars for long sweeps
```

### Scripts Path Convention

All scripts use `SCRIPT_DIR` so outputs are saved next to the script regardless of where Python is launched from:

```python
import os

SCRIPT_DIR = os.path.dirname(os.path.abspath(__file__))
```

---

## 3. NI-DAQmx Driver

The NI USB-6212 requires the NI-DAQmx driver installed on the host PC.

1. Download **NI-DAQmx** from [NI Downloads](https://www.ni.com/downloads).
2. Run the installer and select at minimum: `NI-DAQmx` and `NI-MAX`.
3. Open **NI MAX**.
4. Under `Devices and Interfaces`, verify that `NI USB-6212 "Dev1"` appears.
5. Right-click the device and select **Self-Test** to confirm hardware communication.

---

## 4. NI-VISA for Keithley 2450

The Keithley 2450 SMU is controlled through VISA over USB.

1. Download **NI-VISA** from [NI Downloads](https://www.ni.com/downloads).
2. Install it alongside NI-DAQmx.
3. In NI MAX, verify that the Keithley appears under `Devices and Interfaces --> VISA`.
4. Use the VISA address:

```text
USB0::0x05E6::0x2450::04345889::INSTR
```

Example Python check:

```python
import pyvisa

rm = pyvisa.ResourceManager()
keithley = rm.open_resource('USB0::0x05E6::0x2450::04345889::INSTR')

print(keithley.query('*IDN?'))
```

---

## 5. Verify Everything

From the `python/` directory, run this quick check to confirm the main
interfaces are working:

```python
# NI DAQ
import nidaqmx

with nidaqmx.Task() as task:
    task.ai_channels.add_ai_voltage_chan("Dev1/ai0")
    print("NI DAQ AI0:", task.read())

# STM32 USB CDC
from hardware.cdc_serial import open_port, ping

open_port()
print("STM32 alive:", ping())

# Keithley 2450
import pyvisa

rm = pyvisa.ResourceManager()
k = rm.open_resource('USB0::0x05E6::0x2450::04345889::INSTR')

print("Keithley:", k.query('*IDN?'))
```

---

## 6. `config.py`

Before running any scripts, check `config.py` in the Python root and verify:

```python
DEVICE = "Dev1"              # NI DAQ device name; verify in NI MAX
STM_COM_PORT = "COM4"        # Replace with the port shown in Device Manager
DAC_VERSION = "DAC80508"     # "LTC2600" | "AD5676R" | "DAC80508"
```

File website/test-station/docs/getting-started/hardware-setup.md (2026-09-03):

---
id: hardware-setup
title: Hardware Setup
sidebar_position: 1
---

# Hardware Setup

## Power Supply

The station accepts **9V DC input**, either from a Rigol DP831 bench supply or an external adapter.

### LDO Voltage Adjustment

Two LM1086 LDOs generate the 5V and 3.3V rails using an adjustable resistor divider (R1/R2 for 5V, R3/R4 for 3.3V). Each has a 2K potentiometer that must be trimmed on first use.

1. Connect 9V input -- do **not** connect USB or DUT yet
2. Power on the supply
3. Measure DVDD_5V at the test point with a DMM
4. Trim R2 potentiometer until you read **5.00V +/-20mV**
5. Repeat for DVDD_3V with R4: target **3.30V +/-15mV**
6. Verify DVDD_1V8 (TPS7A2018, fixed -- no adjustment needed)
7. Verify the 2.5V reference (ADR4525CRZ): **2.500V +/-5mV**
8. Disable the bench supply before connecting USB or a DUT.

:::warning USB Latch-Up Risk
During normal USB-controlled operation, connect USB **before** enabling the
bench supply. Hotplugging USB while the board is powered may forward-bias ESD diodes onto the STM32 3.3V IO pins and cause SCR latch-up. At least one latch-up event has occurred requiring days unpowered to recover.

**Power on:** Plug in USB first, then enable the bench power supply.  
**Power off:** Disable the bench power supply first, then unplug USB.
:::

### Power Rails Summary

| Rail | Net name | Source | Powers |
|---|---|---|---|
| 5 V digital | `DVDD_5V` | LM1086 U1 | DAC digital and NI DAQ interface |
| 5 V analog | `AVDD_5V` | `DVDD_5V` through ferrite bead L3 | DAC/TIAs/buffers/ADC analog supplies |
| 3.3 V digital | `DVDD_3V` | LM1086 U2 | STM32 digital, ADC digital, and level translators |
| 3.3 V analog | `AVDD_3V` | `DVDD_3V` through ferrite bead L2 | STM32 analog supply and ADR4525 reference supply|
| 1.8 V digital | `DVDD_1V8` | TPS7A2018 U12 | Low-voltage digital interfaces |
| 2.5 V reference | `REF` | ADR4525CRZ U18 | Reference for DACs and TIA |

---

## Jumper Configuration

### Control Path (DAC Daisy Chain)

Selects whether the DAC80508 5-chip daisy chain is driven by the NI USB-6212 or the STM32.

| Jumper | Position | DAC controlled by |
|---|---|---|
| JP_DAC_SEL | NI | NI USB-6212 (bit-bang DIO, port0/line1-3) |
| JP_DAC_SEL | STM | STM32H743 (PE11 SDI, PE12 SCLK, PE14 CS) |

Only one path should be active at a time.

### DAC Reference Select

A 0 Ohm resistor jumper selects internal or external reference for the DAC80508.
When populated, the REF pin connects to the ADR4525CRZ external 2.5V reference.
When removed, the internal 2.5V reference is used. Both give 0-5V output range (gain=2).

When the 0 Ohm jumper is populated, ensure the firmware and Python driver are
configured to use the external reference -- two voltage sources contending on the
REF pin will pull it to an intermediate voltage and corrupt DAC output accuracy.
On the NI path use `dac_initialize(use_external_ref=True)`. On the STM32 path the
firmware disables the internal reference when external is selected.

### DIO Direction and Voltage (SN74LVC8T245)

Two SN74LVC8T245 translators handle DIO -- one for NI DAQ DIO0-7, one for STM32 DIO0-7.
Each has two jumper controls:

**Direction -- NI DAQ translator (JP9, DIR pin referenced to VCCA):**

| Jumper | DIR pin | Data flow | Effect |
|---|---|---|---|
| JP9 populated | HIGH (`VCCA`) | A → B | NI DAQ reads DUT |
| JP9 removed | LOW (`GND`) | B → A | NI DAQ drives DUT |

**Direction -- STM32 translator (JP33, DIR pin referenced to VCCA):**

| Jumper | DIR pin | Data flow | Effect |
|---|---|---|---|
| JP33 populated | HIGH (`VCCA`) | A → B | STM32 reads DUT |
| JP33 removed | LOW (`GND`) | B → A | STM32 drives DUT |

**Voltage -- Side A (DUT-facing):**

| Jumper | DUT-side voltage |
|---|---|
| JP_VB = 1.8 | 1.8V |
| JP_VB = 3.3 | 3.3V |
| JP_VB = 5.0 | 5.0V |

NI DAQ DIO runs on 5V. STM32 DIO runs on 3.3V.

---

## DUT Connection

Devices under test connect through a three-stage ZIF40 chain:

```
Motherboard (4x ZIF40 female)
  --> Daughter board (4x ZIF40 male + ZIF40 female)
        --> DUT adapter --> Device Under Test
```

1. Select the correct DUT adapter for your package type
2. Insert DUT into the adapter -- verify pin 1 orientation
3. Connect adapter to the ZIF40 female connector on the daughter board
4. Connect daughter board to the motherboard ZIF40 connectors
5. Before applying power, set all DAC outputs to 0V

:::warning
Always ramp bias voltages slowly to the operating point after connecting the DUT.
Never remove a DUT while bias voltages are applied.
:::

---

## SWD Programming Port

The STM32 firmware is loaded via SWD using an STLINK-V3MINIE debugger.

| Pin | Signal |
|-----|---|
| 1 | DVDD_3V (3.3V target power sense) |
| 2 | SWDIO |
| 3 | SWCLK |
| 4 | SWO |
| 5 | NRST |
| 6 | GND |

Connect the STLINK before powering the board. After flashing, the STM32 enumerates as a USB CDC virtual COM port
(for example, `COM4`; VID `0x0483`, PID `0x5740`).

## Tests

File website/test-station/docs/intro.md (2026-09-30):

---
id: intro
title: Introduction
sidebar_position: 1
---

# Automated Analog and Neuromorphic Integrated Circuits Test-Station

Characterizing fabricated analog and neuromorphic ICs often requires separate instruments, software interfaces, and repeated manual setup. These steps are slow and make results difficult to compare across devices. The AIMLAB test station combines a custom measurement board, STM32 firmware, and Python control to make bias generation, acquisition, and data analysis more repeatable.

This project is supported in part by a Research Coordination Network (RCN) grant from the National Science Foundation (NSF), grant no. **2332166**.

## What the Station Does

The station generates programmable DC bias across 40 independent channels, provides 24-bit voltage acquisition, measures current down to the nanoamp range, and captures
transient waveforms at up to 3.2 MSPS -- all from a single Python session. Two
independent control paths (NI USB-6212 and STM32H743) share the same hardware and
can be selected by jumper, giving flexibility for different measurement needs.

DUTs connect through a ZIF40 adapter chain -- motherboard to daughter board to
package-specific adapter -- making it straightforward to swap between device types
without rewiring the measurement hardware.

## Measurement Capabilities

**MOSFET characterization** is fully implemented and validated. The pipeline extracts
threshold voltage (Vth), transconductance (gm), output characteristics (Id-Vds family
of curves), and body diode forward voltage -- all automatically from a three-test
sequence with no rewiring between tests. Bias points for the output sweep are set
automatically from the Vth extracted in the transfer curve test.

**Op-amp characterization** covers DC gain, offset voltage (Vos), linearity (INL),
output swing, common-mode input range (CMR), DC power supply rejection (PSRR), input
bias current (Ib, Ios), and step response. The step response pipeline captures at
3.2 MSPS using the STM32 internal ADC with DMA, resolving slew rate and overshoot
on a sub-microsecond timescale. All tests run from a single Python class with
consistent save/plot/JSON output structure.

## Hardware Platform

The station is built around five purpose-designed subsystems:

- **40-channel DAC** (5x DAC80508, 16-bit, 0-5V) for programmable bias generation,
  with per-channel RC filters on the last two chips for noise-sensitive measurements
- **8-channel precision ADC** (2x ADS131A04, 24-bit, 476 nV/LSB) with DMA streaming
  up to 62.5 kSPS and live data transfer to the PC over USB
- **Transimpedance amplifier** (OPA3S328, switchable 2k/20k/200k/2M Ohm feedback)
  for current measurement from microamps to milliamps, calibrated against a Keithley 2450
- **STM32H743 MCU** at 480 MHz providing USB CDC control, fast burst ADC capture,
  GPIO, and SPI2 DMA -- all accessible from Python over a simple ASCII command protocol
- **NI USB-6212** providing 16-channel 16-bit analog input at 400 kS/s, two analog
  outputs, 8 general-purpose digital I/O lines, and hardware counter/trigger via PFI

All subsystems are documented with hardware specs, firmware API, Python API, and
measured performance results.

## Where to Start

- **Setting up the hardware** -- [Hardware Setup](./getting-started/hardware-setup)
- **Installing Python and firmware** -- [Software Setup](./getting-started/software-setup)
- **Understanding the hardware** -- [System Overview](./subsystems/subsystems-overview)
- **Running a MOSFET test** -- [MOSFET Measurements](./measurements/mosfet/mosfet-overview)
- **Running an op-amp test** -- [Op-Amp Measurements](./measurements/opamp/opamp-overview)

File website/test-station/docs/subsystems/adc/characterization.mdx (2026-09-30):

---
id: characterization
title: Characterization
sidebar_label: Characterization
sidebar_position: 2
---

# ADC Characterization

## Overview

The ADC subsystem was characterized to evaluate:

1. ADS131A04 noise versus oversampling ratio,
2. the effect of RC-filter capacitance on measurement noise,
3. the effect of the OPA4388 input buffer, and
4. two-point DC accuracy.

The ADS131A04 results are also compared with the NI USB-6212, STM32H743 internal ADC,
and Keithley DAQ6510 measurements to show the precision/speed tradeoff across the test station.

## Measurement Setup

A precision ADR4525 reference was used as the approximately 2.5 V DC source. The reference
voltage used for DC-error calculations was measured with the DAQ6510 as:

**Reference voltage used for DC-error calculations: 2.499940308 V.**

Each ADS configuration was measured with:

- **ZERO:** differential input shorted to measure offset and intrinsic noise.
- **ADR4525:** approximately 2.5 V applied to measure signal noise and two-point DC error.

All tested RC filters use a **100 Ω series resistor**. The configurations were:

| Configuration | Buffer |
|---|---|
| 100 Ω + 10 nF | OPA4388 enabled |
| 100 Ω + 1 nF | OPA4388 enabled |
| 100 Ω + 4.7 nF | OPA4388 enabled |
| 100 Ω + 4.7 nF | OPA4388 bypassed |

This arrangement allows the **10 nF versus 1 nF** results to compare filter capacitance,
while the two **4.7 nF** configurations isolate the effect of the input buffer.

The primary ADS operating points were OSR4096, OSR256, OSR128, and OSR32.

## Noise versus OSR

Increasing OSR strongly reduces the ADS131A04 input-referred noise floor.

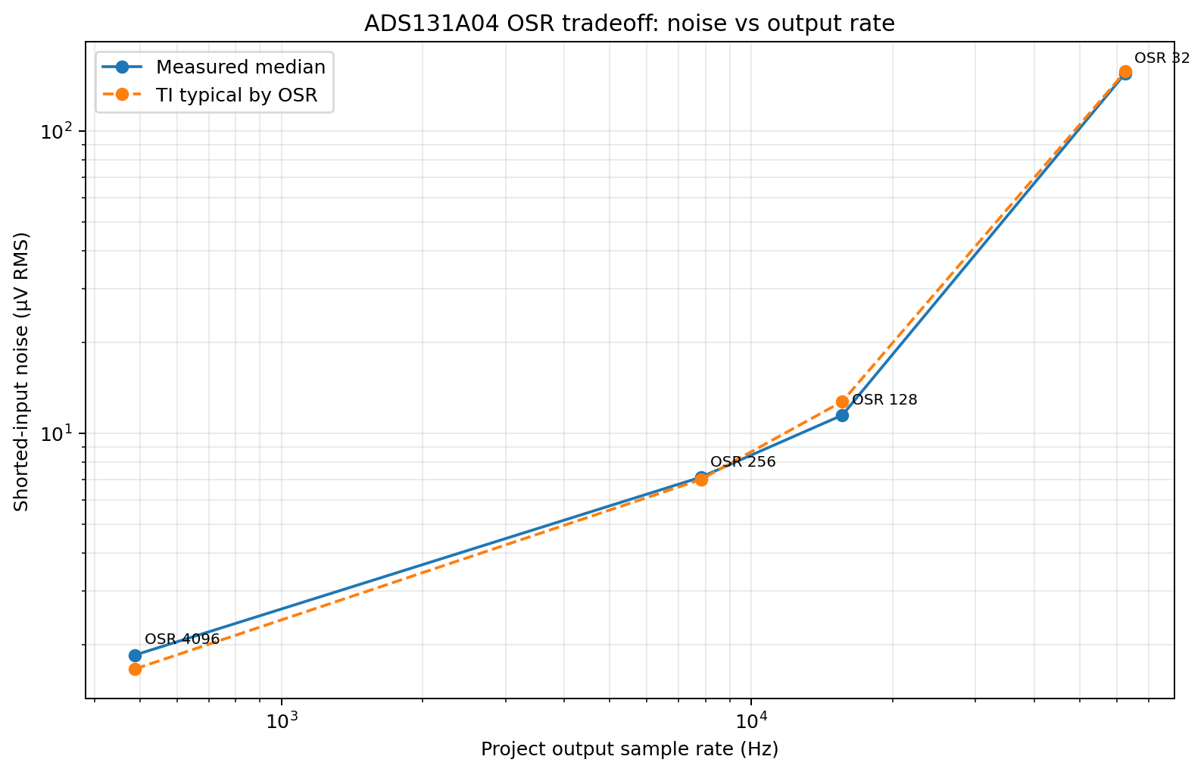
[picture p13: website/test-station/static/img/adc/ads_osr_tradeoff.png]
ADS131A04 OSR noise tradeoff


| OSR | Project rate | Measured median ZERO noise | Datasheet typical | Error vs datasheet |
|----:|---:|---:|---:|---:|
| 4096 | 488.281 S/s | 1.85 µV RMS | 1.66 µV RMS | +11.4% |
| 256 | 7.8125 kS/s | 7.15 µV RMS | 7.02 µV RMS | +1.9% |
| 128 | 15.625 kS/s | 11.47 µV RMS | 12.72 µV RMS | -9.8% |
| 32 | 62.5 kS/s | 154.83 µV RMS | 156.92 µV RMS | -1.3% |

The measurements closely follow the expected OSR-dependent noise behavior. The comparison
is made by OSR; the project modulator-clock condition is not identical to the datasheet
test condition, so this is an OSR-based performance comparison rather than an exact
replication of the datasheet test setup.

## Datasheet Comparison

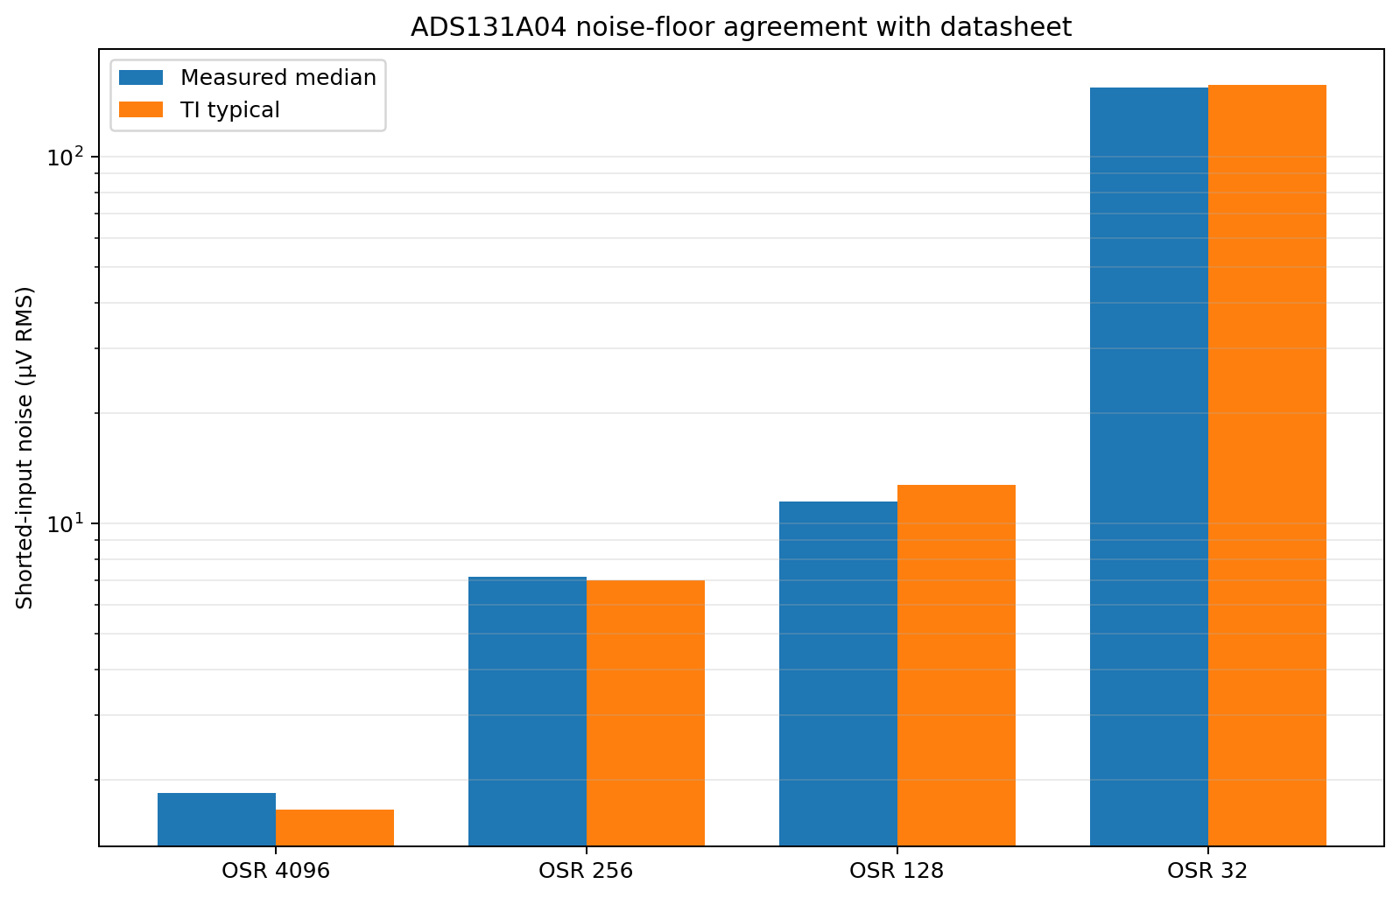
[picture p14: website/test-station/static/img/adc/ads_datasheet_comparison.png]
ADS131A04 measured noise versus datasheet


Across the tested shorted-input measurements, the converter noise floor is close to the
expected typical performance. OSR256, OSR128, and OSR32 are within a few to roughly ten
percent of the corresponding typical values.

This agreement indicates that the ADC subsystem is operating close to the expected
converter noise floor.

## Input Filter Comparison

The filter comparison keeps the resistor fixed at **100 Ω** and the OPA4388 buffer
**enabled**, while changing only the capacitor from **1 nF** to **10 nF**.

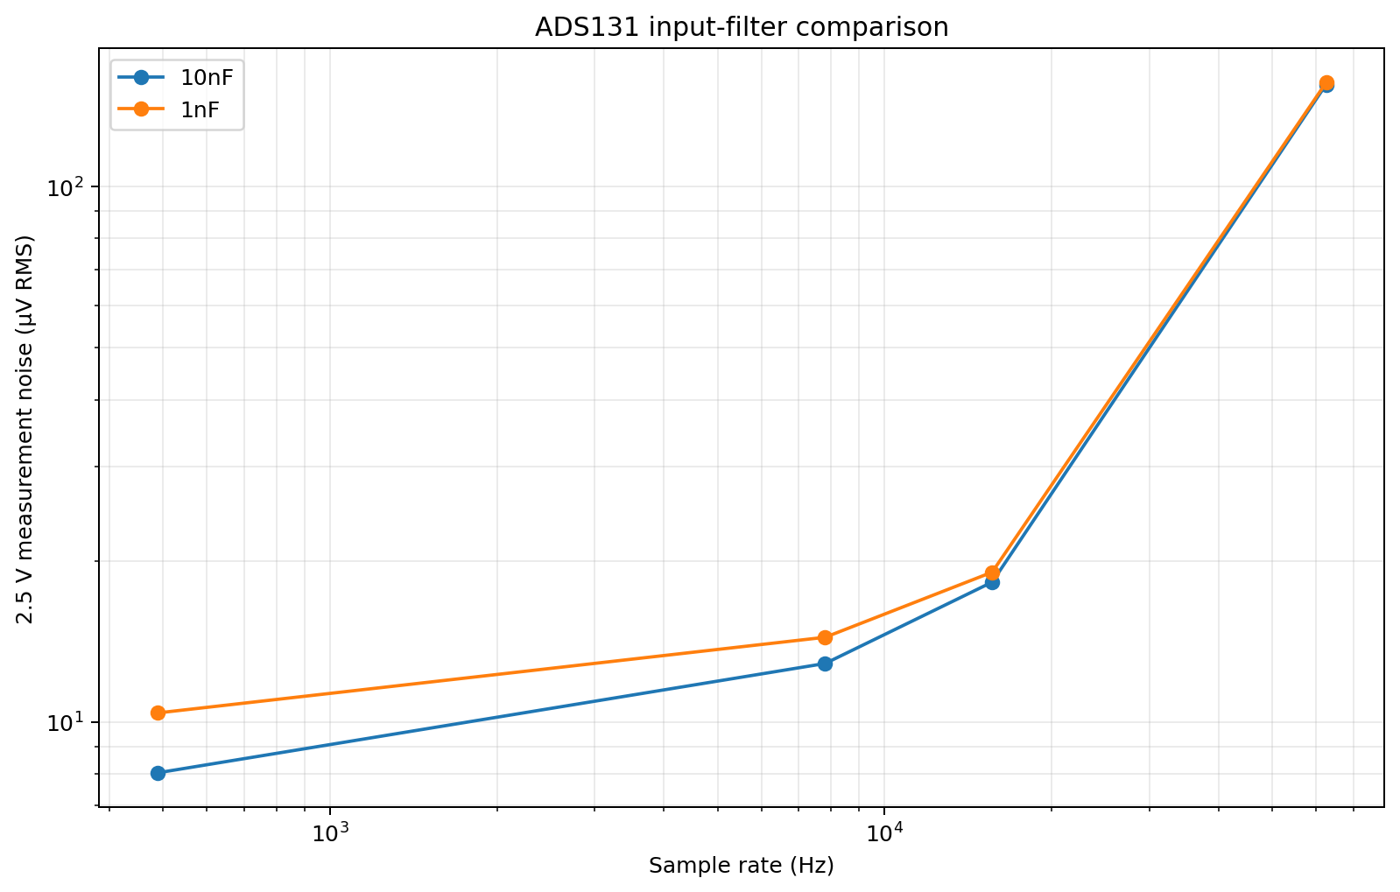
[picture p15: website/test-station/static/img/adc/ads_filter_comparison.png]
ADS131A04 10 nF versus 1 nF


| Rate | 100 Ω + 10 nF signal noise | 100 Ω + 1 nF signal noise | 10 nF, 1–200 Hz | 1 nF, 1–200 Hz |
|-----:|---:|---:|---:|---:|
| 488.281 S/s | 8.04 µV RMS | 10.40 µV RMS | 4.49 µV RMS | 7.00 µV RMS |
| 7.8125 kS/s | 12.87 µV RMS | 14.41 µV RMS | 4.91 µV RMS | 6.25 µV RMS |
| 15.625 kS/s | 18.26 µV RMS | 19.06 µV RMS | 6.06 µV RMS | 6.52 µV RMS |
| 62.5 kS/s | 155.13 µV RMS | 156.33 µV RMS | 5.25 µV RMS | 7.87 µV RMS |

The **100 Ω + 10 nF filter is preferred** for precision measurements. It gives lower
reference-signal noise and lower 1–200 Hz integrated noise than the otherwise comparable
100 Ω + 1 nF configuration across the tested operating points.

At the recommended OSR256 setting, the 10 nF filter measured approximately
**12.87 µV RMS** signal noise and **4.91 µV RMS** integrated noise from 1–200 Hz.

## Buffer Comparison

The buffer comparison uses the same **100 Ω + 4.7 nF RC filter** in both cases.

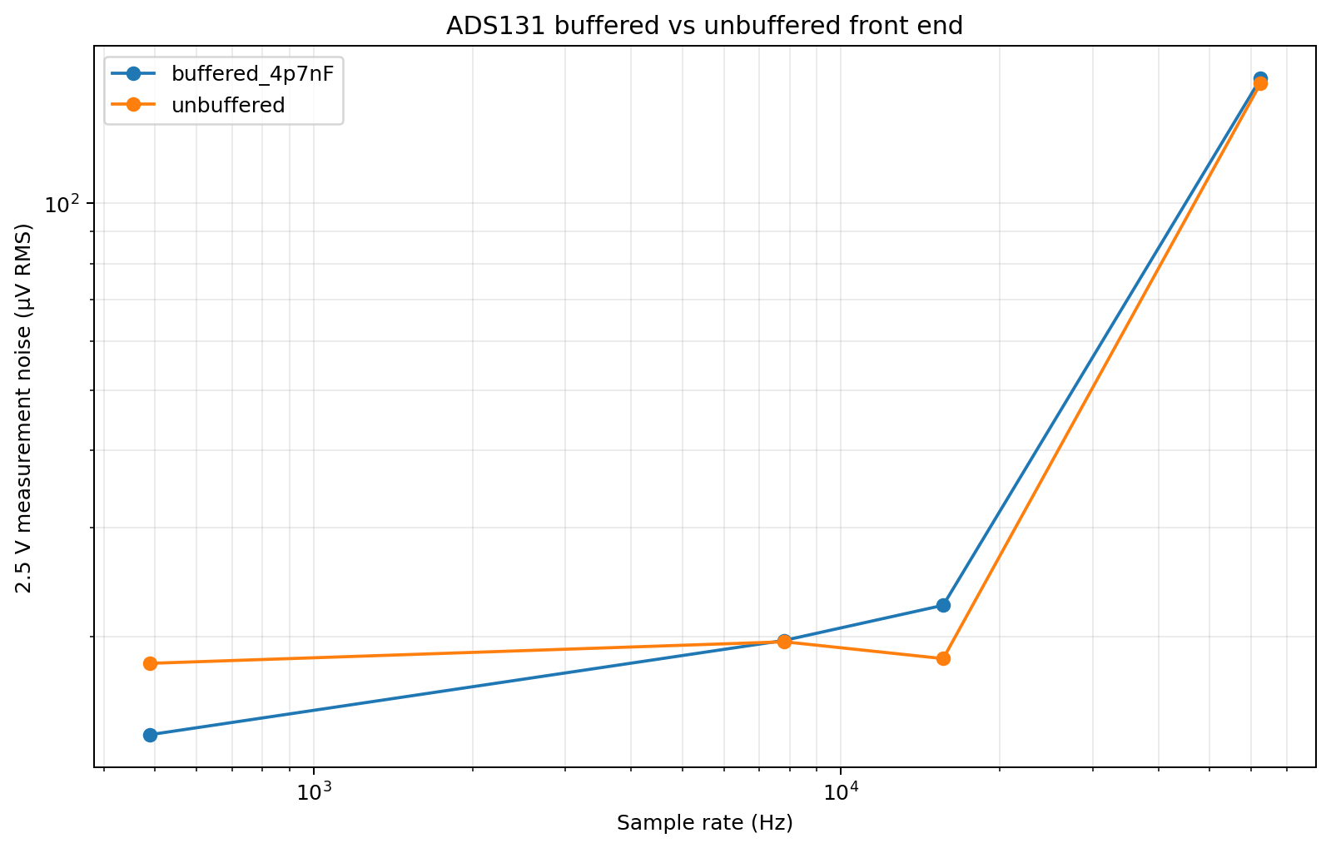
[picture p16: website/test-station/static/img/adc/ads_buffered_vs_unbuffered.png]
ADS131A04 buffered versus unbuffered


| Rate | Buffered signal noise | Buffer-bypassed signal noise | Buffered DC error | Buffer-bypassed DC error |
|-----:|---:|---:|---:|---:|
| 488.281 S/s | 13.89 µV RMS | 18.11 µV RMS | -2164.5 ppm | -837.8 ppm |
| 7.8125 kS/s | 19.73 µV RMS | 19.62 µV RMS | -2162.4 ppm | -858.1 ppm |
| 15.625 kS/s | 22.47 µV RMS | 18.43 µV RMS | -2165.7 ppm | -876.0 ppm |
| 62.5 kS/s | 158.92 µV RMS | 156.21 µV RMS | -2165.9 ppm | -706.1 ppm |

The buffer does not produce a large broadband-noise penalty, but the buffered 4.7 nF
configuration shows an approximately **-0.216% residual DC error**, compared with roughly
**-0.086%** at OSR256 for the buffer-bypassed 4.7 nF configuration.

The buffer therefore remains useful when input isolation or source impedance requires it,
while the measured DC offset/gain behavior should be considered when absolute accuracy is
important.

## DC Accuracy

ADS131 DC accuracy is reported after applying the matched ZERO measurement as an offset
correction. At OSR256, the configuration-level results are approximately:

| Configuration | Two-point DC error |
|---|---:|
| 100 Ω + 10 nF, buffered | ~0.076% |
| 100 Ω + 1 nF, buffered | ~0.080% |
| 100 Ω + 4.7 nF, buffered | ~0.216% |
| 100 Ω + 4.7 nF, buffer bypassed | ~0.086% |

The 10 nF and 1 nF filter configurations show similar two-point DC accuracy, while the
buffered 4.7 nF configuration shows the largest systematic error.

## Recommended ADS131A04 Configuration

For general precision measurements, the best tested filter configuration is:

**OPA4388 buffered + 100 Ω + 10 nF, operated at OSR256 / 7.8125 kS/s.**

| Goal | Configuration | Rate | ZERO noise | 2.5 V signal noise | 1–200 Hz noise |
|---|---|-----:|---:|---:|---:|
| Minimum noise | 100 Ω + 10 nF, OSR4096 | 488.281 S/s | ~2.1 µV RMS | ~8.0 µV RMS | ~4.5 µV RMS |
| **Recommended precision** | **100 Ω + 10 nF, OSR256** | **7.8125 kS/s** | **~7.1 µV RMS** | **~12.9 µV RMS** | **~4.9 µV RMS** |
| Higher bandwidth | 100 Ω + 10 nF, OSR128 | 15.625 kS/s | ~11.4 µV RMS | ~18.3 µV RMS | ~6.1 µV RMS |
| Maximum ADS rate | 100 Ω + 10 nF, OSR32 | 62.5 kS/s | ~154.7 µV RMS | ~155.1 µV RMS | ~5.3 µV RMS |

OSR256 provides the best general balance between noise and sample rate. OSR4096 is
preferred when minimum noise is more important than bandwidth.

## System Context

The test station provides acquisition systems with different precision/speed tradeoffs.

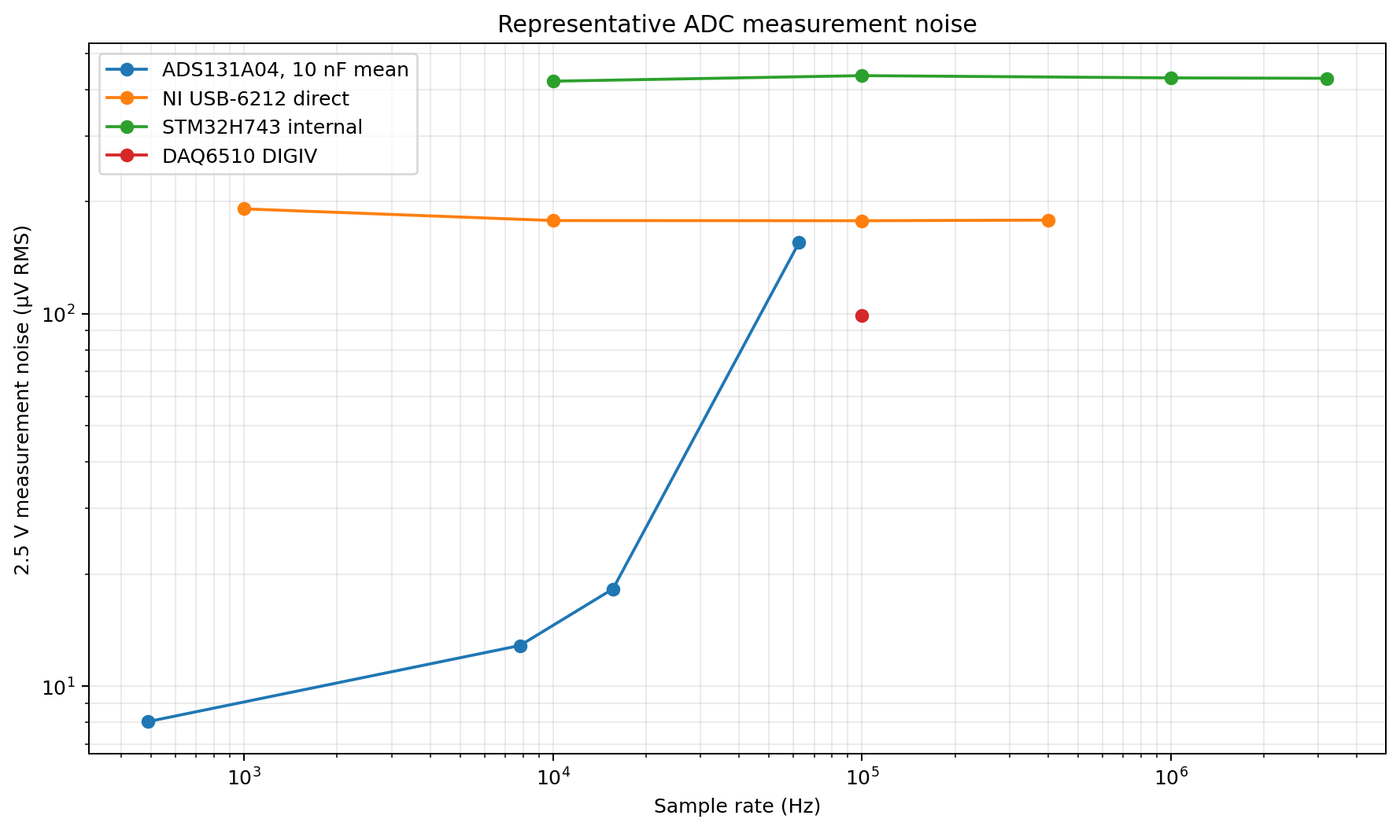
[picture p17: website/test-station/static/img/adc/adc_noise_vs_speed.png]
ADC noise versus speed


| Acquisition system | Representative rate | Representative measured signal noise | Primary role |
|---|---:|---:|---|
| ADS131A04, 100 Ω + 10 nF | 7.8125 kS/s | 12.87 µV RMS | Precision / low-noise acquisition |
| DAQ6510 DIGIV | 100 kS/s | 98.68 µV RMS | Laboratory reference / digitizer |
| NI USB-6212 direct | 400 kS/s | 178.29 µV RMS | Higher-rate external acquisition |
| STM32H743 internal ADC | 3.2 MS/s | 428.29 µV RMS | Fast onboard transient capture |

## Summary

The characterization supports four main conclusions:

- ADS131A04 shorted-input noise closely follows the expected datasheet trend across the
  tested OSRs.
- With the resistor fixed at **100 Ω** and the buffer enabled, **10 nF** performs better
  than **1 nF** for precision measurements.
- The **4.7 nF buffered versus buffer-bypassed** comparison shows that buffering has only
  a modest effect on broadband noise but a larger effect on two-point DC accuracy.
- **OSR256 / 7.8125 kS/s** with the tested **100 Ω + 10 nF buffered configuration** is the
  recommended general precision operating point.

For hardware architecture, firmware, and Python usage, return to the
[ADC subsystem overview](./).

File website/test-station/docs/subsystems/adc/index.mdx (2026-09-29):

---
id: adc
title: ADC
sidebar_position: 5
---

# ADC -- Precision Voltage Measurement

## Overview

Two ADS131A04 ADCs provide eight differential input channels with 24-bit
conversion. The STM32 communicates with both ADCs through SPI2 and supports
DMA-based acquisition. Each motherboard input channel includes an optional
external OPA4388 unity-gain buffer followed by an RC anti-aliasing filter.

Blocking acquisition can read all eight channels sequentially. Because both
ADCs share SPI2 and the current DMA implementation selects one ADC at a time,
continuous DMA streaming captures four simultaneous channels from one chip.

With the current clock configuration, the highest tested streaming rate is
62.5 kSPS per channel at OSR32. Offset calibration is available for all eight
channels to remove residual system offsets. For low-noise voltage measurement,
the characterized default is **OSR256 / 7.8125 kSPS** with the **OPA4388 enabled**
and a **100 Ω + 10 nF RC input filter**.

## Schematic

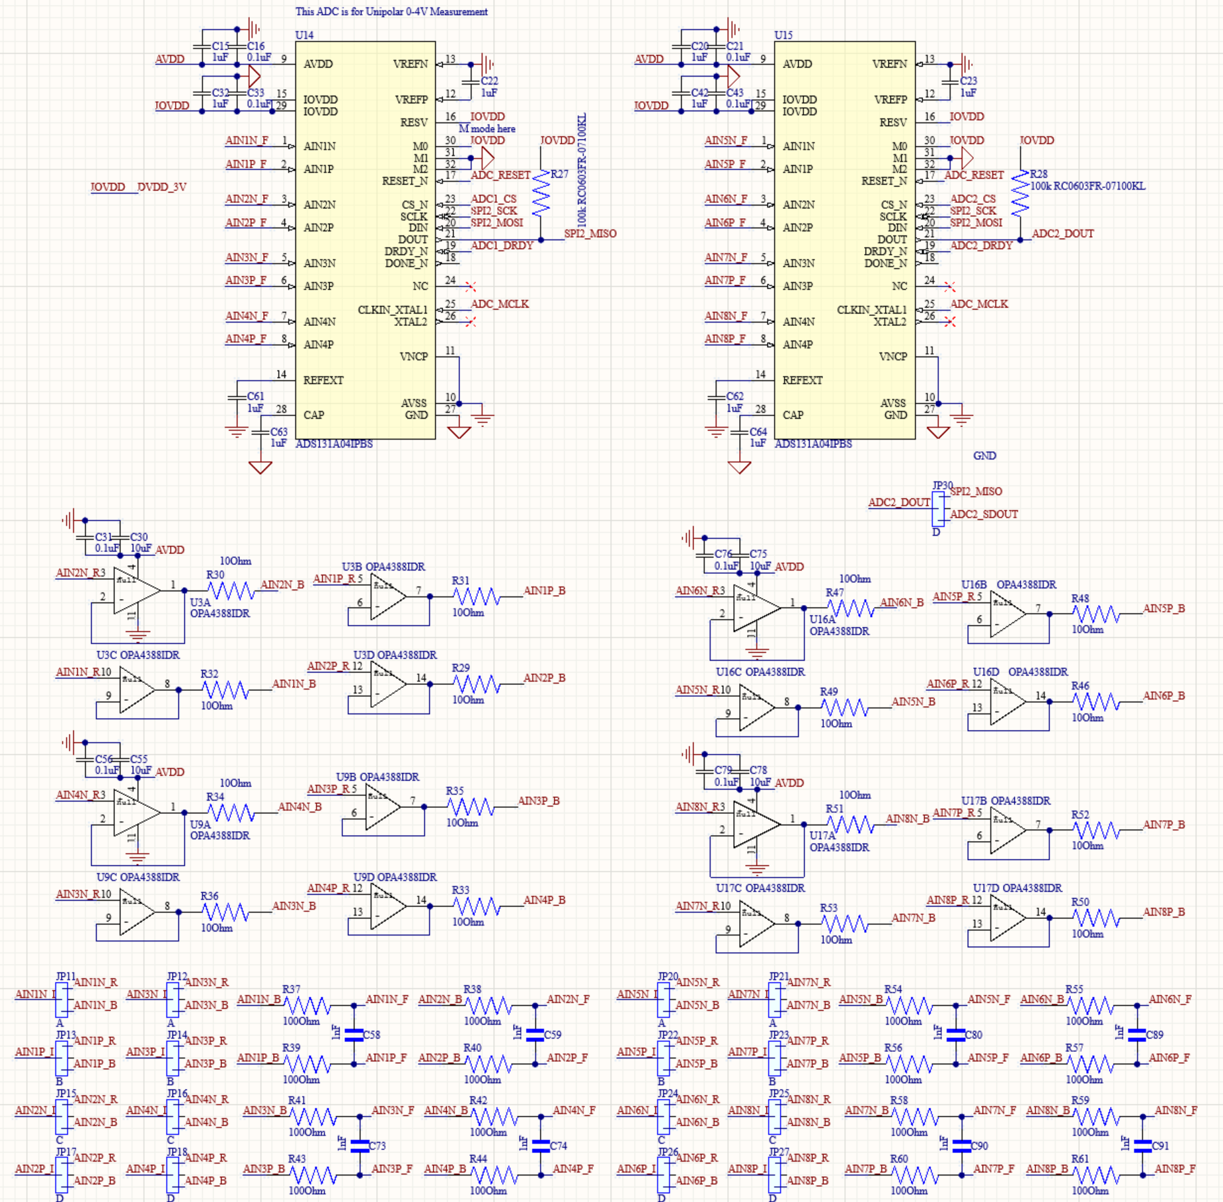
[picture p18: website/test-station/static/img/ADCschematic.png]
ADC Schematic


## Key Specifications

| Parameter | Value |
|---|---|
| Resolution | 24-bit |
| Channels | 4 differential per chip, 8 total (2 chips) |
| Input range | +/-4.0V differential (0-4V single-ended) |
| Reference | Internal 4.0V (AVDD=5V) |
| LSB size | 476 nV |
| Default data rate | 8.0 kSPS (OSR_256) |
| Max reliable data rate | 62.5 kSPS (OSR_32, DMA streaming) |
| MCLK | 8 MHz (STM32 MCO1, PA8) |
| Interface | SPI2 + DMA1 Stream3 |
| Recommended precision front end | OPA4388 enabled, 100 Ω + 10 nF RC filter |

### Data Rate Options

The following rates use the current 2 MHz modulator clock:

| OSR | Data rate | Typical use |
|-----|---|---|
| 4096 | 0.488 kSPS | Lowest-noise DC acquisition |
| 1024 | 1.953 kSPS | Low-frequency measurements |
| 400 | 5.000 kSPS | TIA B_20K range |
| 256 | 7.8125 kSPS | Default voltage acquisition |
| 128 | 15.625 kSPS | Higher-bandwidth acquisition |
| 32 | 62.500 kSPS | Highest tested DMA rate |

### Noise versus OSR

The measured ADS131A04 noise follows the expected oversampling tradeoff:
higher OSR reduces the converter noise floor while lowering the available
output data rate.

ADS131A04 OSR noise tradeoff

| OSR | Project data rate | Measured median shorted-input noise | TI typical |
|-----|---:|---:|---:|
| 4096 | 488.281 S/s | 1.85 µV RMS | 1.66 µV RMS |
| 256 | 7.8125 kS/s | 7.15 µV RMS | 7.02 µV RMS |
| 128 | 15.625 kS/s | 11.47 µV RMS | 12.72 µV RMS |
| 32 | 62.5 kS/s | 154.83 µV RMS | 156.92 µV RMS |

The close agreement with the datasheet trend indicates that the precision ADC
path is operating near the expected converter noise floor. **OSR256** is used
as the default precision setting because it retains several-kilohertz output
bandwidth while keeping the measured shorted-input noise near **7 µV RMS**.
OSR4096 is preferred when minimum noise is more important than bandwidth.

## Hardware Configuration

### Pin Assignment

| Signal | STM32 Pin | Notes |
|---|---|---|
| SPI2 SCLK | PB13 | Shared by both chips |
| SPI2 MISO | PB14 | Shared -- one chip active at a time |
| SPI2 MOSI | PB15 | Shared by both chips |
| CS1 | PE1 | Chip 1, active low |
| CS2 | PE0 | Chip 2, active low |
| DRDY1 | PE2 | EXTI2, falling edge triggers DMA |
| DRDY2 | PE3 | EXTI3, falling edge triggers DMA |
| RESET | PE4 | Shared, active low |
| MCLK | PA8 | MCO1 output, 8 MHz |

### Signal Conditioning

Each differential input pair includes an optional external OPA4388 unity-gain
buffer followed by an RC anti-aliasing filter.

For the quad OPA4388, the input offset voltage is ±2.25 µV typical and
±8 µV maximum at a 5.5 V supply. Its zero-drift architecture provides stable
low-frequency performance and very low 1/f noise. The buffer can be bypassed
using a solder jumper when a direct input path is desired.

For general precision measurements, characterization showed the best overall
result with the **OPA4388 enabled and a 100 Ω + 10 nF RC filter**. At OSR256
(7.8125 kSPS), the 10 nF configuration averaged approximately **7.09 µV RMS**
shorted-input noise, **12.87 µV RMS** while measuring the 2.5 V reference, and
**4.91 µV RMS** integrated over 1–200 Hz. The 10 nF and 1 nF filter comparison
was performed with the buffer enabled, while the 4.7 nF configuration was used
to compare buffered and buffer-bypassed operation. See
[ADC Characterization](./characterization) for the full comparison.

### DMA Streaming

When a conversion completes, the ADS131A04 asserts DRDY low, triggering an EXTI interrupt on the STM32. DMA immediately pulls all 15 bytes of the SPI frame (status + 4 channel samples) into non-cacheable SRAM without CPU involvement. Completed frames are written into a 256-slot ring buffer, which a background task drains into binary USB CDC packets. On the PC, `read_dma()` unpacks 24-bit samples into numpy arrays and updates a live plot in real time.
Because the two ADCs share SPI2 and the current DMA implementation selects
one chip at a time, DMA streaming captures four simultaneous channels from
one ADC. `ADS131A04_ReadBoth()` and the Python `read_all()` method read all
eight channels sequentially.

## Firmware

Driver files: `ads131a04.c`, `ads131a04.h`

```c
void    ADS131A04_HWReset(void);                                    // assert/release shared RESET pin
uint8_t ADS131A04_Init(uint8_t chip, ADS131_OSR_t osr);            // configure chip, enable all 4 channels, returns 1 on success
void    ADS131A04_SetOSR(uint8_t chip, ADS131_OSR_t osr);          // change data rate on running chip
uint8_t ADS131A04_ReadFrame(uint8_t chip, ADS131_Frame_t *frame);  // blocking single read, waits for DRDY
uint8_t ADS131A04_ReadBoth(ADS131_Frame_t *f1, ADS131_Frame_t *f2); // read both chips in sequence
```

OSR constants range from `ADS131_OSR_4096` (0.5 kSPS) to `ADS131_OSR_256` (8 kSPS, default) to `ADS131_OSR_32` (62.5 kSPS max).
DMA functions `ADS131A04_DMA_StartChip()` and `ADS131A04_DMA_RxComplete()` are called automatically by the EXTI and DMA ISRs.

## Python API (`ads131a04.py`)

```python
from config import STM_COM_PORT
from hardware.ads131a04 import ADS131

adc = ADS131(port=STM_COM_PORT)

# -- Setup --
adc.load_cal()                 # load saved offset calibration (run once at session start)
adc.set_osr(chip=1, osr=256)   # set data rate: 8.0 kSPS default
adc.set_osr(chip=1, osr=32)    # or 62.5 kSPS for max speed

# -- Calibration (short AINxP to AINxN before running) --
adc.calibrate()                # measure and save offsets for both chips -> cal_ads131.json
adc.clear_cal()                # remove all offset corrections

# -- Single reads --
v = adc.read_single(chip=1, ch=1)        # one channel -> float volts
frame = adc.read_frame(chip=1)           # all 4 channels -> {1: V, 2: V, 3: V, 4: V}
data = adc.read_all()                    # all 8 channels (both chips) -> {'C1CH1': V, ...}

# -- Buffered acquisition (ASCII, moderate speed) --
v, t = adc.read_buffered(chip=1, num_frames=100)
# v: numpy array (4, N) -- one row per channel, t: timestamps in seconds

# -- DMA streaming (binary, max throughput, live plot) --
v, t = adc.read_dma(chip=1, num_frames=50000, duration=30.0,
                    display_ch=1, csv_filename="capture.csv")

# -- Continuous live plot (runs until window closed or duration reached) --
v, t = adc.read_continuous(chip=1, ch=1, duration=None,
                           window_sec=5.0, csv_filename="live.csv")

# -- Diagnostics --
adc.selftest()                 # read status registers + one frame per chip
adc.status(chip=1)             # returns {'ID': '0x04', 'STAT': '0x00', ...}
```

## Measured Performance

For normal precision acquisition, **OSR256 / 7.8125 kSPS** with the recommended
**OPA4388-buffered 100 Ω + 10 nF** front end provides the best overall balance of
noise and throughput. At this setting, the 10 nF configuration measured about
**7.1 µV RMS** shorted-input noise, **12.9 µV RMS** while measuring the 2.5 V
reference, and **4.9 µV RMS** integrated over 1–200 Hz.

For lower-bandwidth measurements, OSR4096 reduces the shorted-input noise to
about **1.85 µV RMS**. For higher bandwidth, OSR128 and OSR32 increase the output
rate to 15.625 kSPS and 62.5 kSPS respectively, with the expected increase in
converter noise.

Detailed filter, buffer, DC-accuracy, and cross-system comparisons are provided
on the [ADC Characterization](./characterization) page.

**5 kHz sine at 62.5 kSPS** -- clean reconstruction with ~12 samples per cycle over a 5ms window.

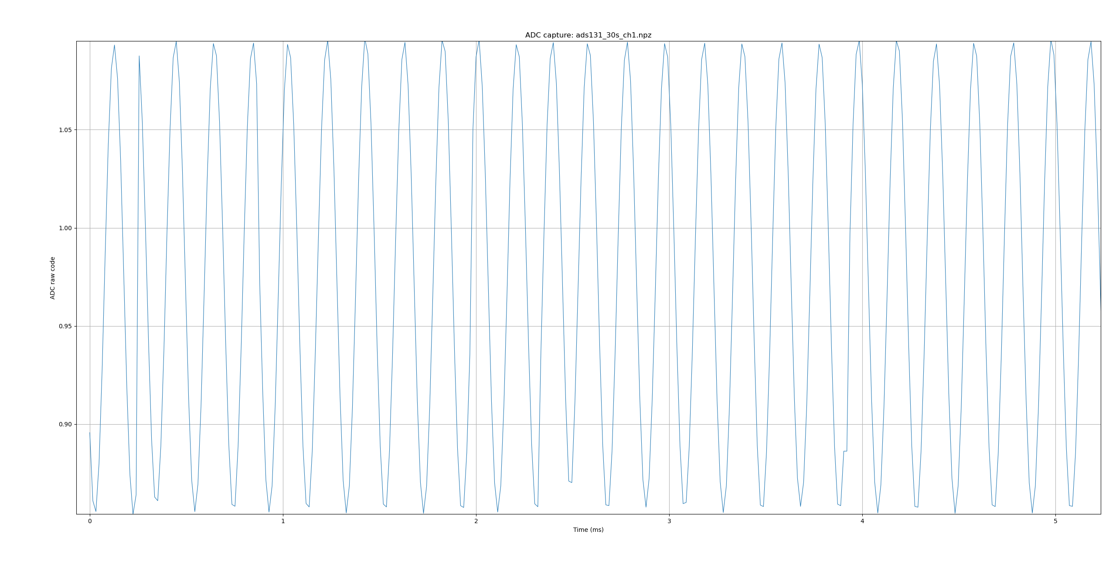
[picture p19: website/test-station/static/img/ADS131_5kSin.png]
5kHz sine at 62.5kSPS


**10 mVpp signal at ~8 kSPS** -- 10 mVpp signal resolved clearly above the noise floor, with smooth consistent waveform shape across a 0.4s window.

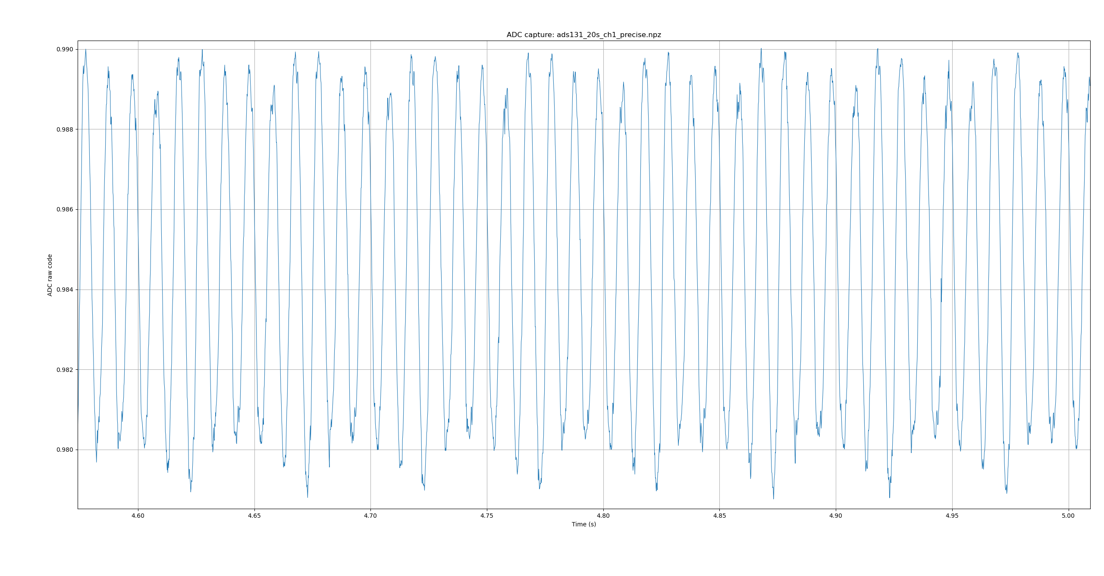
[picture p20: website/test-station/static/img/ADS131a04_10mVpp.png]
10mVpp at 8kSPS


### Detailed Characterization

Noise versus OSR, datasheet agreement, RC-filter selection, buffered versus
buffer-bypassed operation, and DC-accuracy measurements are documented on the
**[ADC Characterization](./characterization)** page.

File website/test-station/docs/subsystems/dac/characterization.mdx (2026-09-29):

---
title: DAC Characterization
sidebar_label: Characterization
---

# DAC Characterization

## Overview

The V3 DAC subsystem was characterized to verify board-level static accuracy,
controller independence, reference selection, output-filter behavior, and
system-level noise performance. The measurements below use the DAC80508
subsystem together with the Keithley DAQ6510 as the precision measurement
instrument.

## Test Setup and Method

| Item | Configuration |
|---|---|
| DAC | DAC80508, 16 bit, 0-5 V |
| DAC count | 5 devices, 40 total channels |
| Control paths | NI USB-6212 and STM32H743 |
| Reference options | Internal 2.5 V reference or ADR4525 external reference |
| Static test | Sparse DC sweep across the programmed range |
| Noise acquisition | DAQ6510 digitize mode, 100 kS/s, 60 s |
| Main noise bias point | 2.5 V |
| Additional bias points | Approximately 0.5 V and 4.5 V on selected runs |
| Instrument baseline | DAQ6510 short-input measurement |
| DAQ6510 short-input RMS floor | 78.4 uVrms |

Static linearity is reported as a **sparse interior best-fit residual**. The
near-5 V endpoint is not used as the primary linearity metric because output
headroom near the positive supply can dominate the full-range endpoint error.

## Measurement Interpretation

:::caution Noise Measurement Floor

Noise measurements include the Keithley DAQ6510 measurement chain. The
DAQ6510 short-input baseline is approximately **78.4 uVrms**, while many of
the DAC measurements are approximately 100-120 uVrms. The broadband noise
results are therefore partly instrument-floor limited.

The reported RMS and spectral-density values should be interpreted as
**measured system-level values and practical upper bounds**, rather than as a
direct measurement of the intrinsic DAC80508 noise floor.

:::

## Static Accuracy

All selected configurations were monotonic over the sampled static sweep. The
external-reference and filtered configurations produced sub-LSB interior
best-fit residuals.

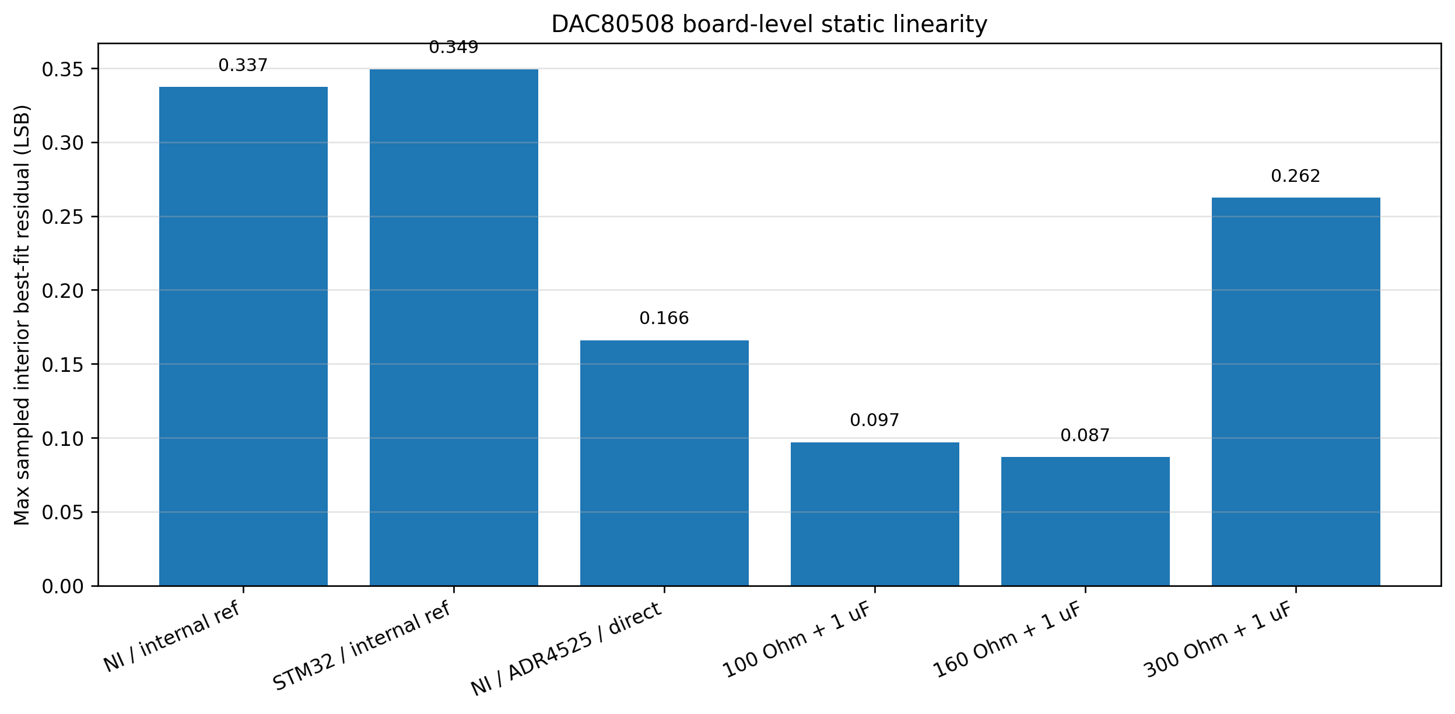
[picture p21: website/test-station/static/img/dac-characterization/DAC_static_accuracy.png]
DAC static accuracy


| Configuration | Max sampled interior residual | Interior gain error | Max interior absolute error |
|---|---|---|---|
| NI + internal reference | 0.337 LSB | -558.4 ppm | 2.248 mV |
| STM32 + internal reference | 0.349 LSB | -581.8 ppm | 2.278 mV |
| NI + ADR4525, direct | 0.166 LSB | -440.5 ppm | 1.686 mV |
| ADR4525 + 100 Ohm + 1 uF | 0.097 LSB | -479.9 ppm | 1.804 mV |
| ADR4525 + 160 Ohm + 1 uF | 0.087 LSB | -697.3 ppm | 2.308 mV |
| ADR4525 + 300 Ohm + 1 uF | 0.262 LSB | -824.8 ppm | 3.207 mV |

The **160 Ohm + 1 uF** path produced the smallest measured sparse residual.
However, static residual alone was not used to select the preferred system
configuration.

## NI vs STM32 Control Path

The NI and STM32 control paths were compared using the internal reference. The
two paths produced closely comparable static and noise results, indicating that
the STM32 control path does not materially degrade DAC output performance.

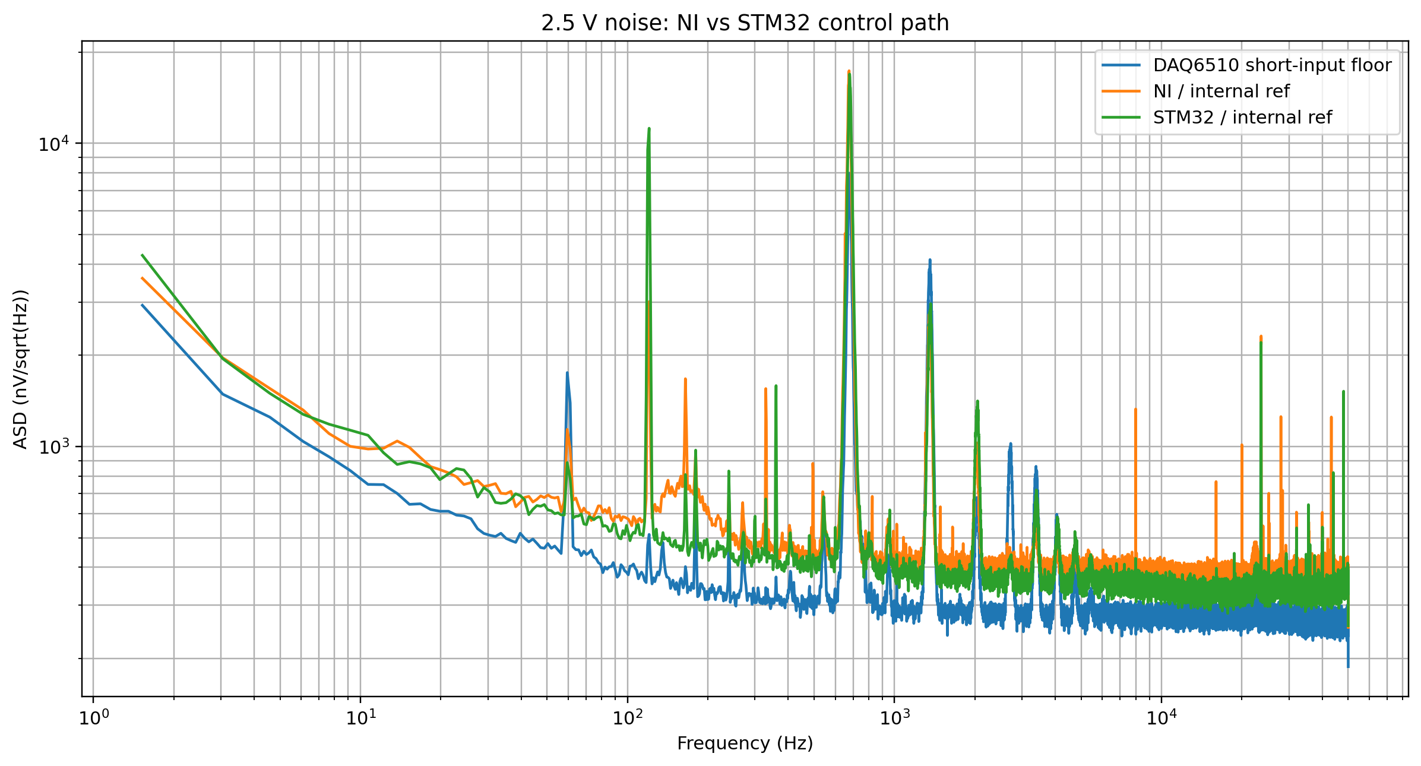
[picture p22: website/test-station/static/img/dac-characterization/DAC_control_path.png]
NI vs STM32 DAC control


| Metric | NI control | STM32 control |
|---|---|---|
| Max sampled interior residual | 0.337 LSB | 0.349 LSB |
| Interior gain error | -558.4 ppm | -581.8 ppm |
| DC error at 2.5 V | -0.963 mV | -1.104 mV |
| Measured system RMS at 2.5 V | 116.4 uVrms | 111.5 uVrms |
| Measured system ASD at 60 Hz | 1140 nV/sqrt(Hz) | 886 nV/sqrt(Hz) |
| Measured system ASD at 1 kHz | 418 nV/sqrt(Hz) | 417 nV/sqrt(Hz) |
| Measured system ASD at 10 kHz | 371 nV/sqrt(Hz) | 347 nV/sqrt(Hz) |

The close agreement supports use of the STM32H743 as the normal deployed
controller while retaining the NI interface for laboratory control and debug.

## Internal vs External Reference

The ADR4525 external reference improved the measured static result relative to
the DAC80508 internal reference and also modestly reduced several measured
noise-density values.

Internal vs external reference

| Metric | Internal reference | ADR4525 external reference |
|---|---|---|
| Max sampled interior residual | 0.337 LSB | 0.166 LSB |
| Interior gain error | -558.4 ppm | -440.5 ppm |
| DC error at 2.5 V | -0.963 mV | -0.660 mV |
| Measured system RMS at 2.5 V | 116.4 uVrms | 110.1 uVrms |
| Measured system ASD at 60 Hz | 1140 nV/sqrt(Hz) | 1049 nV/sqrt(Hz) |
| Measured system ASD at 1 kHz | 418 nV/sqrt(Hz) | 361 nV/sqrt(Hz) |
| Measured system ASD at 10 kHz | 371 nV/sqrt(Hz) | 350 nV/sqrt(Hz) |

The ADR4525 is therefore used as the preferred precision reference for the
characterized output configuration.

## Output Filter Comparison

Several 1 uF RC output filters were compared at 2.5 V. The filter comparison
shows a tradeoff between static accuracy, mains-frequency susceptibility, and
higher-frequency attenuation.

DAC output filter comparison

DAC output noise spectra

All RMS and ASD values below are measured system-level values and include the DAQ6510 measurement contribution.

| Output path | Sampled residual | RMS noise | 60 Hz ASD | 1 kHz ASD | 10 kHz ASD |
|---|---|---|---|---|---|
| ADR4525 direct | 0.166 LSB | 110.1 uVrms | 1049 nV/sqrt(Hz) | 361 nV/sqrt(Hz) | 350 nV/sqrt(Hz) |
| 100 Ohm + 1 uF | 0.097 LSB | 110.5 uVrms | 556 nV/sqrt(Hz) | 340 nV/sqrt(Hz) | 323 nV/sqrt(Hz) |
| 160 Ohm + 1 uF | 0.087 LSB | 110.6 uVrms | 980 nV/sqrt(Hz) | 345 nV/sqrt(Hz) | 312 nV/sqrt(Hz) |
| 300 Ohm + 1 uF | 0.262 LSB | 98.8 uVrms | 2085 nV/sqrt(Hz) | 303 nV/sqrt(Hz) | 282 nV/sqrt(Hz) |
| 1 kOhm + 1 uF | 0.209 LSB | 110.1 uVrms | 7778 nV/sqrt(Hz) | 289 nV/sqrt(Hz) | 312 nV/sqrt(Hz) |

The 300 Ohm path gives lower measured high-frequency ASD, but its static
accuracy is worse and its 60 Hz component is larger. The 1 kOhm path gives
stronger low-pass action at higher frequency, but it also shows a large and
reproducible 60 Hz component.

The 1 kOhm behavior was confirmed by the original channel, a repeat
measurement, and a second 1 kOhm channel, with approximately
7.78-8.08 uV/sqrt(Hz) measured at 60 Hz. It is therefore retained as a real
path/setup susceptibility rather than treated as a single bad capture.

## Recommended Configuration

The preferred precision configuration is:

**ADR4525 external reference + 100 Ohm + 1 uF output filter**

Recommended DAC configuration

This configuration was selected as the best overall engineering tradeoff:

- **0.097 LSB** maximum sampled interior best-fit residual.
- **-479.9 ppm** interior gain error.
- **1.804 mV** maximum measured interior absolute error.
- **556 nV/sqrt(Hz)** at 60 Hz.
- **340 nV/sqrt(Hz)** at 1 kHz.
- **323 nV/sqrt(Hz)** at 10 kHz.
- Sampled monotonic behavior across the characterized static sweep.

The 160 Ohm + 1 uF path gives a slightly smaller static residual
(0.087 LSB), but the 100 Ohm + 1 uF path shows lower 60 Hz pickup and better
overall DC error behavior. The 100 Ohm path is therefore used as the preferred
default rather than selecting the filter from a single metric.

Return to the [DAC subsystem page](./).

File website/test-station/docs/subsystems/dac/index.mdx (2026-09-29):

---
id: dac
title: DAC
sidebar_label: Overview
sidebar_position: 4
---

# DAC -- Bias Voltage Generation

## Overview

Five 16-bit, 8-channel DACs provide 40 independently programmable DC bias
channels over a 0-5 V range. The devices are connected in a five-chip daisy
chain using an SPI-compatible serial protocol. The chain can be controlled by
either the NI USB-6212 or the STM32H743, selected by a shunt jumper.

The current V3 design uses the DAC80508. It can operate from the DAC's internal
2.5 V reference or from the on-board ADR4525 precision reference. DAC4 and DAC5
also include per-channel RC output filtering for noise-sensitive bias outputs.

## Schematic

DAC Schematic

## Hardware Configuration

### Reference Selection

A 0 Ohm resistor jumper controls whether the DAC80508 uses its internal 2.5 V
reference or the external ADR4525CRZ. When the resistor is populated, the REF
pin connects to the ADR4525 output. When removed, the internal reference is
active. Both configurations provide the same 0-5 V output range.

:::warning External Reference Selection

When the external ADR4525 reference is connected, the DAC80508 internal
reference must be disabled. Enabling both references simultaneously causes
the two voltage sources to contend and can corrupt the DAC output.

For the NI control path, initialize the DAC using
`dac_initialize(use_external_ref=True)`. The STM32 firmware must likewise
disable the internal reference when the external-reference jumper is
populated.

:::

### Output Filtering

DAC4 and DAC5 include per-channel RC output-filter footprints. The V3
characterization compared direct output and several 1 uF filter combinations,
including 100 Ohm, 160 Ohm, 300 Ohm, and 1 kOhm series resistance.

The preferred precision configuration is:

**ADR4525 external reference + 100 Ohm + 1 uF output filter**

This configuration gives the best overall balance between measured static
accuracy, 60 Hz susceptibility, and higher-frequency noise behavior. The
160 Ohm + 1 uF path produced the smallest sampled static residual, but the
100 Ohm + 1 uF path is retained as the preferred system configuration.

### Control Path Selection

| Jumper | DAC driven by |
|---|---|
| NI position | NI USB-6212 (port0/line1-3, software-timed) |
| STM position | STM32H743 (PE11 SDI, PE12 SCLK, PE14 CS) |

## Measured Performance

The table below summarizes the current V3 board-level characterization using
the preferred ADR4525 + 100 Ohm + 1 uF output path unless otherwise noted.

:::note Measurement Floor

Noise measurements include the DAQ6510 measurement chain. The DAQ6510
short-input RMS floor was approximately **78.4 uVrms**, so broadband noise
measurements near this level are partly instrument-floor limited.

The spectral-density values below are therefore reported as measured
**system-level values and practical upper bounds**, rather than as direct
measurements of the intrinsic DAC80508 noise floor. The static/DC metrics are
not limited by the DAQ6510 noise floor in the same way.

:::

### Static and DC Performance

| Parameter | Measured result |
|---|---|
| Output range | 0-5 V |
| Resolution | 16 bit, 76.3 uV nominal LSB |
| Recommended configuration | ADR4525 + 100 Ohm + 1 uF |
| Recommended-path sampled interior residual | 0.097 LSB |
| Recommended-path interior gain error | -479.9 ppm |
| Recommended-path max interior absolute error | 1.804 mV |
| Sampled monotonicity | Yes |
| Best sampled interior residual | 0.087 LSB, 160 Ohm + 1 uF |

### Noise Performance

| Parameter | Measured result |
|---|---|
| DAQ6510 short-input RMS floor | 78.4 uVrms |
| Measured system RMS at 2.5 V | 110.5 uVrms |
| Measured system ASD at 60 Hz | 556 nV/sqrt(Hz) |
| Measured system ASD at 1 kHz | 340 nV/sqrt(Hz) |
| Measured system ASD at 10 kHz | 323 nV/sqrt(Hz) |

Recommended DAC configuration

For the complete static, controller, reference, and output-filter comparisons,
see [DAC Characterization](./characterization).

## DAC Versions and Specifications

Three DAC families have been used across board generations, all with the same
five-chip daisy-chain topology. Each version uses serial data, clock, and
chip-select or synchronization signals, with serial-data-output connections
between adjacent devices. The LTC2600 and AD5676R require an additional
hardware clear or reset signal, while the DAC80508 supports software reset.

The values below are device-level datasheet specifications and are kept
separate from the board-level measured results above.

| Parameter | LTC2600 (V1) | AD5676R (V2) | DAC80508 (V3) |
|---|---|---|---|
| Resolution | 16-bit | 16-bit | 16-bit |
| Channels per chip | 8 | 8 | 8 |
| Output range | 0 to VREF | 0-2.5 V or 0-5 V | 0-5 V (gain=2) |
| DNL | +/-1 LSB max | +/-1 LSB max | +/-1 LSB max |
| INL | +/-2 LSB typ | +/-3 LSB max | +/-1 LSB max |
| Gain error | +/-0.3% FSR typ | +/-0.06% FSR max | +/-0.1% FSR max |
| Internal reference | None | 2.5 V, 2 ppm/°C typ | 2.5 V, 2 ppm/°C typ |
| Noise density | 120 nV/sqrtHz @ 1 kHz | 80 nV/sqrtHz @ 10 kHz (ext ref) | 78 nV/sqrtHz @ 1 kHz |
| Noise (0.1-10 Hz) | -- | 6 uVpp | 14 uVpp |
| Settling time | 9.7 us (1/4 to 3/4 scale) | 5 us typ, 8 us max | 5 us (1/4 to 3/4 scale) |
| Slew rate | 0.8 V/us | 0.8 V/us | 1.8 V/us |
| Short-circuit current | +/-15 mA min | 40 mA | 30 mA |
| Supply range | 2.5-5.5 V | 2.7-5.5 V | 2.7-5.5 V |
| Serial-clock limit | 50 MHz | 50 MHz | Up to 25 MHz in daisy-chain mode |
| Temperature range | -40 to 85 °C | -40 to 125 °C | -40 to 125 °C |
| Interface | Serial interface with hardware clear | SPI-compatible interface with hardware reset | SPI-compatible interface with software reset |

The active version is selected in `config.py`:

```python
DAC_VERSION = "DAC80508"   # "LTC2600" | "AD5676R" | "DAC80508"
```

## Firmware

Driver files: `dac80508.c`, `dac80508.h`

```c
// Initialize all 5 chips -- call once at startup
void DAC80508_Init(void);

// Set one channel by raw 16-bit code (0x0000 = 0V, 0xFFFF = 5V)
void DAC80508_SetChannel(uint8_t chip, uint8_t channel, uint16_t code);

// Set one channel by voltage (0.0-5.0V, clamped)
void DAC80508_SetVoltage(uint8_t chip, uint8_t channel, float voltage);

// Zero all 40 outputs
void DAC80508_ClearAll(void);
```

## Python API

### NI Path (`dac_dac80508.py`)

```python
from hardware import dac_initialize, set_voltage, dac_clear_all, get_voltage, dac_print_state

# Initialize with internal reference (default)
dac_initialize()

# Initialize with external ADR4525 reference instead
dac_initialize(use_external_ref=True)

# Set chip 2, channel 3 to 1.8V
set_voltage(2, 3, 1.8)

# Read back last commanded voltage (Python shadow state, not hardware readback)
v = get_voltage(2, 3)

# Print 5x8 voltage table
dac_print_state()

# Zero all outputs and close NI task
dac_clear_all()
```

### STM32 Path (`stm_dac80508.py`)

```python
from hardware.stm_dac80508 import initialize, set_voltage, set_all, clear_all, print_state

# Zero all outputs at startup
initialize()

# Set chip 1, channel 1 to 1.0V
set_voltage(1, 1, 1.0)

# Set all 40 outputs to the same voltage
set_all(2.5)

# Zero all outputs
clear_all()

# Print 5x8 shadow state table
print_state()
```

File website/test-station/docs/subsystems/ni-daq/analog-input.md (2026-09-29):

---
id: ni-daq-analog-input
title: Analog Input
sidebar_position: 1
---

# NI DAQ -- Analog Input

## Overview

The USB-6212 provides 16 analog input channels (AI0-AI15), 16-bit, up to 400 kS/s.
AI0-AI3 are buffered on the motherboard with a unity-gain OPA4388IDR before reaching
the DAQ connector. AI4-AI15 connect directly to the edge connector without buffering.
Channels can be configured as 16 single-ended or 8 differential in software.
Both the buffered and direct input paths were characterized up to 400 kS/s. The direct
inputs showed slightly lower measured noise, while AI0-AI3 provide the OPA4388 buffer
when source isolation or buffering is useful.

## Key Specifications (USB-6212 AI)

| Parameter | Value |
|---|---|
| Channels | 16 single-ended or 8 differential |
| Resolution | 16-bit |
| Max sample rate | 400 kS/s aggregate |
| Input ranges | +/-0.2V, +/-1V, +/-5V, +/-10V |
| CMRR (DC-60Hz) | 100 dB |
| Input impedance (on) | >10 GOhm in parallel with 100 pF |
| Noise (10V range) | 295 uVrms |
| Absolute accuracy (10V range) | 2,710 uV full scale |
| Absolute accuracy (0.2V range) | 89 uV full scale |
| Small signal bandwidth | 1.5 MHz |
| Overvoltage protection | ±30 V on up to two AI pins while powered |

## Signal Conditioning -- OPA4388 Input Buffer

AI0-AI3 pass through a unity-gain OPA4388IDR buffer on the motherboard. The OPA4388
is a zero-drift precision op-amp specifically suited for ADC buffering -- its zero-drift
architecture eliminates 1/f noise, meaning noise performance stays flat down to DC,
which is important for low-frequency and DC characterization measurements.

| Parameter | OPA4388 Value |
|---|---|
| Offset voltage | ±2.25 µV typical, ±8 µV maximum |
| Offset drift | +/-0.005 uV/degC |
| Noise density | 7 nV/sqrtHz @ 1kHz (no 1/f noise) |
| Low freq noise | 0.14 uVpp (0.1-10Hz) |
| CMRR | 140 dB |
| GBW | 10 MHz |
| Settling time | 2 us to 0.01% |

:::caution Buffered-Channel Input Range

Although the USB-6212 supports bipolar input ranges up to ±10 V, AI0–AI3
pass through an OPA4388 powered from the 5 V analog rail. These buffered
channels are intended for approximately 0–5 V signals. AI4–AI15 connect
directly to the DAQ and retain the native USB-6212 input ranges.
:::

## Python API (`ai.py`)

```python
from hardware import read_single, read_buffered, read_continuous

# Single scan -- one sample per channel
v = read_single(0)                      # ai0 -> float volts
v0, v1, v2 = read_single([0, 1, 2])    # list of channels -> list of floats
all_ch = read_single()                  # all channels from config -> list

# Finite buffered acquisition
volts, times = read_buffered(
    channel=0,
    rate=400_000,        # Hz, max 400 kS/s single channel
    num_samples=4000,
)
# volts: numpy array shape (num_samples,)
# times: numpy array of timestamps in seconds from 0

# Continuous live plot with optional CSV
volts, times = read_continuous(
    channel=0,
    rate=400_000,
    duration=10.0,       # seconds, or None to run indefinitely
    window_sec=0.5,      # rolling window width on live plot
    csv_filename='capture.csv'
)
```

### Configuration (`config.py`)

```python
AI_CHANNELS        = list(range(8))     # ai0-ai7
AI_TERMINAL_CONFIG = "SingleEnded"      # "SingleEnded" | "Differential" | "Pseudodiff"
AI_VOLTAGE_RANGE   = (-10.0, 10.0)     # (min_V, max_V)
AI_DEFAULT_RATE    = 400_000            # Hz
AI_DEFAULT_SAMPLES = 4_000
```

## Measured Performance

Single-channel acquisition is confirmed from **1 kS/s to 400 kS/s** with live streaming
and CSV recording. `read_continuous()` uses hardware-clocked acquisition, allowing
continuous operation at the full 400 kS/s single-channel rate.

The characterization compared a representative **OPA4388-buffered input** with a
**direct USB-6212 input** using shorted-input and approximately 2.5 V reference
measurements.

NI USB-6212 buffered versus direct input noise

| Rate | Buffered signal noise | Direct signal noise | Buffered 1–200 Hz noise | Direct 1–200 Hz noise |
|-----:|---:|---:|---:|---:|
| 1 kS/s | 189.42 µV RMS | 191.15 µV RMS | 125.86 µV RMS | 124.95 µV RMS |
| 10 kS/s | 185.19 µV RMS | 177.83 µV RMS | 58.62 µV RMS | 55.84 µV RMS |
| 100 kS/s | 185.74 µV RMS | 177.62 µV RMS | 49.16 µV RMS | 46.11 µV RMS |
| 400 kS/s | 185.66 µV RMS | 178.29 µV RMS | 48.26 µV RMS | 45.11 µV RMS |

At **400 kS/s**, the direct input measured approximately **178 µV RMS** signal noise,
while the buffered input measured approximately **186 µV RMS**. The direct path is
therefore slightly quieter in the tested configuration, while both retain the full
high-rate acquisition capability.

Two-point DC accuracy at approximately 2.5 V was also good for both configurations:
approximately **-100 ppm** for the direct input and **-88 ppm** for the representative
buffered input at 400 kS/s.

For general high-rate acquisition where the source can directly drive the USB-6212,
**AI4-AI15** provide the native bipolar input range and slightly lower measured noise.
**AI0-AI3** provide the OPA4388 buffer when buffering or source isolation is useful.

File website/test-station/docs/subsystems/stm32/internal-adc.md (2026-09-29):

---
id: stm32-internal-adc
title: Internal ADC
sidebar_position: 2
---

# STM32 -- Internal ADC

## Overview

The STM32H743 has four internal ADC channels on PA1-PA4, 16-bit, 0-3.3V range.
These serve two distinct roles: slow single-sample reads for monitoring on-board signals
via USB CDC, and high-speed burst capture for step response and transient measurements.
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

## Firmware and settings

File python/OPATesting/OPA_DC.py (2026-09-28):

# Project: Automated Analog and Neuromorphic Integrated Circuits Test Station
# Author: Kaiyuan (Sam) Kang
#
# Licensing Terms: This program is licensed under the Creative Commons
# Attribution-NonCommercial 4.0 International License (CC BY-NC 4.0).
# You are free to share and adapt this program for noncommercial purposes,
# provided that appropriate credit is given, a link to the license is provided,
# and any modifications are indicated. Commercial use requires a separate
# license from the copyright holder. See the LICENSE file for the complete
# license terms.
#
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
"""
measurements/dc.py
==================
DC characterization for a 5-pin op-amp DUT (A+, A-, Aout, V+, V-).
STATUS: validated and finalized on OPA4388, 2026-07 (see "Known-good
results" below). Settling/artifact issues from earlier development are
resolved -- see "Development history" if you hit something that looks
like those symptoms again.

--------------------------------------------------------------------
PHYSICAL CONNECTIONS
--------------------------------------------------------------------
Power
    OPA4388 V+  -> 5.0V (bench supply or Keithley 2450)
    OPA4388 V-  -> AGND
    100nF ceramic + 10uF bulk decoupling right at the V+ pin.
    Sequencing: bring V+ up BEFORE any DAC output is commanded above
    0V; zero the DAC before removing V+. (Same rule as the USB
    hotplug/latch-up guidance elsewhere in this project -- an input
    signal present without its supply properly up can forward-bias
    input ESD/clamp diodes.)

Reference node (Vref = 2.5V)
    Generated by a dedicated ADR4525 reference chip (NOT a DAC
    channel -- do not rely on self.vref alone to make this voltage
    exist in hardware, it is a math constant used only to reconstruct
    Aout from the ADC's differential reading).
    ADR4525 output -> Rg (10k) -> op-amp A- pin
    ADR4525 output -> ADS131A04 AINN (this channel's negative input)

Feedback network (non-inverting, gain = 1 + Rf/Rg = 11 nominal)
    Rg = 10k   : op-amp A- pin  <-> Vref node (ADR4525 output)
    Rf = 100k  : op-amp A- pin  <-> op-amp Aout pin
    (Rg and Rf meet at the A- pin -- that junction is the feedback node.)

Input stimulus
    DAC80508 dac_num/dac_ch (default chip1/ch1, i.e. OUT0) -> A+ pin
    Driven via the NI USB-6212 bit-bang bus (hardware.dac_dac80508),
    NOT the STM32 -- this is a hybrid fixture: DAC on the NI path,
    ADC on the STM32/USB-CDC path, running simultaneously.

Output acquisition (differential, NOT single-ended)
    ADS131A04 AINP (adc_chip/adc_ch) -> op-amp Aout pin
    ADS131A04 AINN (same channel)    -> Vref node (ADR4525 output)
    The ADC channel therefore reports (Aout - Vref) natively; this
    script adds self.vref back to reconstruct the true Aout. This
    keeps the 0..5V single-ended swing inside the ADC's differential
    input range -- feeding Aout single-ended against ADC ground would
    clip the ADC on any output above a few volts.

Ground
    DAC80508 GND, ADS131A04 AVSS/DVSS, STM32 GND, and op-amp V- all
    tie to one common ground point near the ADC (star topology,
    not daisy-chained) -- noise here shows up directly as the
    baseline() noise-floor number.

Unused channels (OPA4388 is a quad package)
    Tie each unused channel's A+ and A- together, connected to the
    Vref node. Leave outputs floating (no load needed). This matters:
    an earlier OPA4197 on this same fixture died, most likely from an
    unused channel railing and stressing the shared V+/V- supply pins
    common to all four internal amplifiers on the die.

--------------------------------------------------------------------
KNOWN-GOOD RESULTS (OPA4388, this fixture, most recent clean run)
--------------------------------------------------------------------
    Gain            : 10.86  (nominal 11, -1.3% -- within resistor tolerance)
    Vos (fixture)   : -1.98 mV  (fixture/resistor-tolerance-limited;
                       chip's real spec is 0.25uV, far below what this
                       rig can resolve -- do not read this as chip Vos)
    INL             : 0.11%, asymmetric (steeper near the +rail) --
                       consistent with real rail-to-rail output-stage
                       compression, not an artifact
    Baseline noise  : ~250uV RMS at the output node

--------------------------------------------------------------------
DEVELOPMENT HISTORY (context for future maintainers)
--------------------------------------------------------------------
Earlier debugging on this fixture found, in order: a loose DAC SPI
daisy-chain connection (output pinned, DAC changes had no effect), a
dead OPA4197 (V- pin measured 4.xV despite being tied to AGND -- an
internal short, most likely from an untied unused channel), and after
swapping to OPA4388, a large decaying leading-edge artifact on the
first ~10 points of every sweep following a rail-to-linear transition
(coarse sweep's saturated tail -> fine sweep's first point). That
artifact was NOT the op-amp (datasheet: ~10us overload recovery, ~2us
settling -- both negligible) -- it was the ADS131A04's own decimation
filter needing real time/samples to flush stale data after a big step.
Fixed via _wait_for_stable(): after any reading near a rail, keep
pulling small ADC batches until several consecutive batch means agree,
rather than guessing a fixed sleep or flush count.

--------------------------------------------------------------------
Covers test sequence steps:
    0. Fixture baseline (no DUT / DUT input held at Vref) -> ADC noise floor
    1. Coarse sweep  -> operating range, clipping, rough gain
    2. Fine sweep+fit -> precise gain, Vos, INL/linearity error, output swing

Hardware bindings (matches your actual driver modules):
    hardware.dac_dac80508  -- module-level functions, NI USB-6212 bus
        initialize(), set_voltage(dac_num, ch_num, voltage), clear_all()
    hardware.ads131a04     -- ADS131 class, STM32 USB CDC bus
        read_buffered(chip, num_frames) -> (voltages[4,n], timestamps)

Usage:
    from measurements.dc import DCTest
    dc = DCTest(dac_num=1, dac_ch=1, adc_chip=1, adc_ch=1, tag="opa4388")
    dc.run_all()

1-indexed channel numbering throughout, matching the rest of the stack.
"""

import os
import csv
import json
import time
import numpy as np
import matplotlib.pyplot as plt

SCRIPT_DIR = os.path.dirname(os.path.abspath(__file__))

import sys
sys.path.insert(0, os.path.join(SCRIPT_DIR, ".."))

import hardware.dac_dac80508 as dacmod
from hardware.ads131a04 import ADS131


class DCTest:
    def __init__(self, dac_num=1, dac_ch=1, adc_chip=1, adc_ch=1,
                 vref=2.5, vpos=5.0, g_nom=11.0,
                 settle_s=0.005, n_avg=64, tag="opa4197",
                 adc: ADS131 = None):
        self.dac_num = dac_num      # DAC80508 chip 1-5
        self.dac_ch = dac_ch        # DAC80508 channel 1-8 (OUT0-OUT7)
        self.adc_chip = adc_chip    # ADS131A04 chip 1-2
        self.adc_ch = adc_ch        # ADS131A04 channel 1-4
        self.vref = vref
        self.vpos = vpos
        self.g_nom = g_nom
        self.settle_s = settle_s    # settle time after each DAC step
        self.n_avg = n_avg          # frames averaged per read point
        self.tag = tag
        self.results = {}
        self._last_aout = None   # tracks whether we're coming out of saturation

        # bring up the NI-based DAC bus once; auto-inits on first
        # set_voltage() too, but explicit here keeps timing predictable
        dacmod.initialize()

        # ADS131() opens the STM32 CDC port and pings the firmware;
        # reuse an existing instance if the caller already has one open
        # (only one CDC port can be open at a time)
        self.adc = adc if adc is not None else ADS131()

    def _dac_set(self, volts):
        """Command A+ input voltage via NI-bus DAC80508 driver."""
        dacmod.set_voltage(self.dac_num, self.dac_ch, volts)

    def _adc_read_n(self, n):
        """
        Return n samples of Aout (volts), reconstructed from the
        differential (Aout - Vref) reading.
        """
        v_arr, _t = self.adc.read_buffered(chip=self.adc_chip, num_frames=n)
        ch_row = v_arr[self.adc_ch - 1]        # index 0..3 for ch 1..4
        return ch_row + self.vref

    def _wait_for_stable(self, batch_n=100, tol_v=2e-5, window=5, max_batches=120):
        """
        Read repeated small batches, keeping a rolling window of the last
        `window` batch means. Only declare stable once that whole window's
        spread (max-min) is within tol_v -- a single lucky adjacent pair
        isn't a strong enough test, since a slow decay can produce small
        step-to-step differences well before it actually reaches its
        asymptote (this is what the previous version got wrong).
        """
        means, row = [], None
        for _ in range(max_batches):
            v_arr, _t = self.adc.read_buffered(chip=self.adc_chip, num_frames=batch_n)
            row = v_arr[self.adc_ch - 1]
            means.append(float(np.mean(row)))
            if len(means) >= window and (max(means[-window:]) - min(means[-window:])) < tol_v:
                return row
        return row  # gave up at max_batches -- still return the last batch

    def _measure_point(self, vin):
        """
        Set input, settle, return (Aout_mean, Aout_std).
        The OPA4388 itself settles in ~2us and recovers from overload in
        ~10us (datasheet spec) -- nowhere near the bottleneck. The lag
        after a big step is downstream of the amplifier (most likely the
        ADS131A04's decimation filter). Wait for the reading to actually
        stabilize after a rail transition rather than guessing a delay.
        """
        near_rail = (self._last_aout is not None and
                     (self._last_aout < 0.1 or self._last_aout > self.vpos - 0.1))
        self._dac_set(vin)
        time.sleep(self.settle_s)
        if near_rail:
            self._wait_for_stable()
        s = self._adc_read_n(self.n_avg)   # now record the real reading
        mean_v = float(np.mean(s))
        self._last_aout = mean_v
        return mean_v, float(np.std(s))

    # -- Step 0: baseline -----------------------------------------------------
    def baseline(self):
        """Hold input at Vref, capture ADC noise floor at the output node."""
        self._dac_set(self.vref)
        time.sleep(0.05)
        self._wait_for_stable()   # flush until the reading actually stabilizes
        s = self._adc_read_n(4096)
        noise_rms = float(np.std(s))
        self.results["baseline"] = {
            "aout_at_vref_mean": float(np.mean(s)),
            "noise_rms_V": noise_rms,
            "noise_rms_uV": noise_rms * 1e6,
            "n_samples": len(s),
        }
        print(f"[0] baseline: Aout(Vin=Vref)={np.mean(s):.6f}V  "
              f"noise_rms={noise_rms*1e6:.2f}uVrms")
        return self.results["baseline"]

    # -- Step 1: coarse sweep -------------------------------------------------
    def coarse_sweep(self, n=41):
        span = (self.vpos / 2.0) / self.g_nom
        vin = np.linspace(self.vref - span * 1.3, self.vref + span * 1.3, n)
        vin = np.clip(vin, 0.0, self.vpos)
        aout = np.array([self._measure_point(v)[0] for v in vin])

        lo_rail, hi_rail = 0.05, self.vpos - 0.05
        linear = (aout > lo_rail) & (aout < hi_rail)
        print(f"[1] coarse: Aout range over sweep = "
              f"{aout.min():.4f}V .. {aout.max():.4f}V  "
              f"(non-rail window is {lo_rail:.2f}V..{hi_rail:.2f}V)")
        if linear.sum() >= 2:
            g_rough = np.polyfit(vin[linear], aout[linear], 1)[0]
            vin_lin = (vin[linear].min(), vin[linear].max())
            vout_lin = (aout[linear].min(), aout[linear].max())
            print(f"[1] coarse: G~{g_rough:.3f}  Vin_linear={vin_lin}  "
                  f"Vout_swing={vout_lin}")
        else:
            g_rough, vin_lin, vout_lin = float("nan"), (None, None), (None, None)
            print("[1] coarse: WARNING -- every point fell outside the "
                  "non-rail window. Aout is saturated across the WHOLE "
                  "sweep, not just at the edges. Check the DC bias point "
                  "(Vin=Vref) directly -- see quick_check.py -- before "
                  "widening or re-running the sweep.")

        self.results["coarse"] = {
            "vin": vin.tolist(), "aout": aout.tolist(),
            "g_rough": g_rough,
            "vin_linear_range": vin_lin,
            "vout_swing": vout_lin,
            "vout_lo_rail_V": float(aout.min()),
            "vout_hi_rail_V": float(aout.max()),
        }
        return self.results["coarse"]

    # -- Step 2: fine sweep + fit --------------------------------------------
    def fine_sweep(self, n=101, guard=0.10):
        c = self.results.get("coarse")
        if not c or c["vin_linear_range"][0] is None:
            raise RuntimeError("run coarse_sweep() first (no linear region found)")

        v0, v1 = c["vin_linear_range"]
        pad = (v1 - v0) * guard
        vin = np.linspace(v0 + pad, v1 - pad, n)
        pts = [self._measure_point(v) for v in vin]
        aout = np.array([p[0] for p in pts])
        astd = np.array([p[1] for p in pts])

        G, b = np.polyfit(vin, aout, 1)

        aout_at_vref = G * self.vref + b
        vos = (aout_at_vref - self.vref) / G

        fit = G * vin + b
        resid = aout - fit
        span = aout.max() - aout.min()
        inl_pct = float(np.max(np.abs(resid)) / span * 100.0)

        self.results["fine"] = {
            "vin": vin.tolist(), "aout": aout.tolist(), "aout_std": astd.tolist(),
            "gain": float(G),
            "gain_nom": self.g_nom,
            "vos_V": float(vos),
            "vos_uV": float(vos * 1e6),
            "inl_max_pct": inl_pct,
            "inl_max_uV_out": float(np.max(np.abs(resid)) * 1e6),
            "resid_V": resid.tolist(),
        }
        print(f"[2] fine: G={G:.4f} (nom {self.g_nom})  "
              f"Vos={vos*1e6:.1f}uV  INL={inl_pct:.3f}% of span")
        return self.results["fine"]

    # -- orchestration + output ----------------------------------------------
    def run_all(self):
        self.baseline()
        self.coarse_sweep()
        try:
            self.fine_sweep()
        except Exception:
            self.save()   # keep baseline+coarse on disk even if this fails
            raise
        self.save()
        self.plot()
        return self.results

    def save(self):
        base = os.path.join(SCRIPT_DIR, f"dc_{self.tag}")
        with open(base + ".json", "w") as f:
            json.dump(self.results, f, indent=2)
        fine = self.results.get("fine")
        if fine:
            with open(base + "_fine.csv", "w", newline="") as f:
                w = csv.writer(f)
                w.writerow(["vin_V", "aout_V", "aout_std_V", "residual_V"])
                for row in zip(fine["vin"], fine["aout"],
                               fine["aout_std"], fine["resid_V"]):
                    w.writerow(row)
        print(f"    saved {base}.json / _fine.csv")

    def plot(self):
        fig, ax = plt.subplots(2, 1, figsize=(8, 8), sharex=False)
        c, fine = self.results.get("coarse"), self.results.get("fine")
        if c:
            ax[0].plot(c["vin"], c["aout"], ".-", label="coarse")
            ax[0].axhline(0.05, ls=":", c="r"); ax[0].axhline(self.vpos - 0.05, ls=":", c="r")
            ax[0].set(xlabel="Vin (V)", ylabel="Aout (V)",
                      title=f"{self.tag}  coarse sweep + swing limits")
            ax[0].legend()
        if fine:
            ax[1].plot(fine["vin"], np.array(fine["resid_V"]) * 1e6, ".-")
            ax[1].set(xlabel="Vin (V)", ylabel="linearity residual (uV out)",
                      title=f"G={fine['gain']:.3f}  Vos={fine['vos_uV']:.1f}uV  "
                            f"INL={fine['inl_max_pct']:.3f}%")
            ax[1].axhline(0, ls=":", c="k")
        fig.tight_layout()
        out = os.path.join(SCRIPT_DIR, f"dc_{self.tag}.png")
        fig.savefig(out, dpi=120)
        print(f"    saved {out}")


if __name__ == "__main__":
    dc = DCTest(dac_num=1, dac_ch=1, adc_chip=1, adc_ch=1, tag="opa4388")
    try:
        dc.run_all()
    finally:
        dacmod.clear_all()   # always zero outputs + close NI task, even on crash

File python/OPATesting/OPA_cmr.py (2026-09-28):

# Project: Automated Analog and Neuromorphic Integrated Circuits Test Station
# Author: Kaiyuan (Sam) Kang
#
# Licensing Terms: This program is licensed under the Creative Commons
# Attribution-NonCommercial 4.0 International License (CC BY-NC 4.0).
# You are free to share and adapt this program for noncommercial purposes,
# provided that appropriate credit is given, a link to the license is provided,
# and any modifications are indicated. Commercial use requires a separate
# license from the copyright holder. See the LICENSE file for the complete
# license terms.
#
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
"""
measurements/cmr.py
====================
Common-mode input range (CMR) for the op-amp DUT.

PHYSICAL SETUP -- DIFFERENT topology than dc.py's gain-11 sweep.
    Unity-gain buffer required so Aout can track the FULL 0..5V input
    range without hitting output clipping at gain=11 (dc.py's coarse
    sweep already showed only ~2.28-2.72V of input survives at gain
    11 -- that's an OUTPUT swing limit, not the INPUT CMR limit this
    script is after).

    Lift Rf (100k) and Rg (10k) off the A- pin entirely.
    Tie A- directly to Aout with a short wire (gain = 1).
    A+  : DAC80508 dac_num/dac_ch, swept 0..Vpos (full range this
          time, not centered on Vref like dc.py).
    ADC : unchanged from dc.py -- AINP=Aout, AINN=Vref. The Vref node
          itself is NOT used as a DUT input in this test (no Rg to
          feed it into), only as the ADC's differential reference.
    Power sequencing: same discipline as always -- V+ down before the
    Rf/Rg rewire, back up after.

With A-=A+=Vin (unity feedback) and Aout=A- ideally, expect Aout==Vin
across the whole sweep. Where that breaks down -- either the input
stage losing common-mode range near a rail, or the output stage's own
swing limit (OPA4388 is genuine RRIO, so expect these two effects to
coincide near the rails rather than show up separately) -- shows up as
a growing error = Aout - Vin.

CAVEAT -- possible ADC range limit, not a DUT limit: Aout-Vref spans
roughly -2.5V to +2.5V across this sweep. Project notes disagree on
whether the ADS131A04's true differential full-scale is +/-4V or
closer to +/-2.44V -- if it's the latter, the extreme ends of this
sweep could clip the ADC itself, not the amplifier. Tell them apart:
real CMR/output-swing failure looks like a smooth, DUT-shaped
saturation curve; ADC clipping looks like the error abruptly pinning
at a flat, constant value right at the edges.

Reuses the settle/flush lesson from dc.py (which needed 4 iterations
to get right) from the start here rather than re-deriving it.
"""

import os
import csv
import json
import time
import numpy as np
import matplotlib.pyplot as plt

SCRIPT_DIR = os.path.dirname(os.path.abspath(__file__))

import sys
sys.path.insert(0, os.path.join(SCRIPT_DIR, ".."))

import hardware.dac_dac80508 as dacmod
from hardware.ads131a04 import ADS131


class CMRTest:
    def __init__(self, dac_num=1, dac_ch=1, adc_chip=1, adc_ch=1,
                 vref=2.5, vpos=5.0, settle_s=0.005, n_avg=64,
                 tag="opa4388", adc: ADS131 = None):
        self.dac_num = dac_num
        self.dac_ch = dac_ch
        self.adc_chip = adc_chip
        self.adc_ch = adc_ch
        self.vref = vref
        self.vpos = vpos
        self.settle_s = settle_s
        self.n_avg = n_avg
        self.tag = tag
        self.results = {}
        self._last_aout = None   # tracks whether we're coming out of saturation

        dacmod.initialize()
        self.adc = adc if adc is not None else ADS131()

    def _dac_set(self, volts):
        dacmod.set_voltage(self.dac_num, self.dac_ch, volts)

    def _adc_read_n(self, n):
        v_arr, _t = self.adc.read_buffered(chip=self.adc_chip, num_frames=n)
        ch_row = v_arr[self.adc_ch - 1]
        return ch_row + self.vref

    def _wait_for_stable(self, batch_n=100, tol_v=2e-5, window=5, max_batches=120):
        """Same convergence-based flush as dc.py -- see that file's
        header for why a fixed sleep or fixed flush count don't work."""
        means, row = [], None
        for _ in range(max_batches):
            v_arr, _t = self.adc.read_buffered(chip=self.adc_chip, num_frames=batch_n)
            row = v_arr[self.adc_ch - 1]
            means.append(float(np.mean(row)))
            if len(means) >= window and (max(means[-window:]) - min(means[-window:])) < tol_v:
                return row
        return row

    def _measure_point(self, vin):
        near_rail = (self._last_aout is not None and
                     (self._last_aout < 0.1 or self._last_aout > self.vpos - 0.1))
        self._dac_set(vin)
        time.sleep(self.settle_s)
        if near_rail:
            self._wait_for_stable()
        s = self._adc_read_n(self.n_avg)
        mean_v = float(np.mean(s))
        self._last_aout = mean_v
        return mean_v, float(np.std(s))

    def sweep(self, n=101, err_threshold_v=0.05):
        """
        Full 0..Vpos sweep at unity gain. Reports the Vin range where
        |Aout-Vin| stays under err_threshold_v -- the empirical
        CMR/output-swing boundary -- plus the typical error within
        that well-behaved region.
        """
        vin = np.linspace(0.0, self.vpos, n)
        self._dac_set(vin[0])
        time.sleep(self.settle_s)
        self._wait_for_stable()   # first point has no prior reading to
                                   # trigger near_rail -- flush unconditionally
        pts = [self._measure_point(v) for v in vin]
        aout = np.array([p[0] for p in pts])
        astd = np.array([p[1] for p in pts])
        err = aout - vin

        ok = np.abs(err) < err_threshold_v
        if ok.sum() >= 2:
            vin_ok = (float(vin[ok].min()), float(vin[ok].max()))
            err_ok_mean = float(np.mean(err[ok]))
            err_ok_rms = float(np.std(err[ok]))
        else:
            vin_ok = (None, None)
            err_ok_mean = err_ok_rms = float("nan")

        self.results["cmr"] = {
            "vin": vin.tolist(), "aout": aout.tolist(),
            "aout_std": astd.tolist(), "err_V": err.tolist(),
            "err_threshold_V": err_threshold_v,
            "vin_ok_range": vin_ok,
            "err_ok_mean_V": err_ok_mean,
            "err_ok_rms_V": err_ok_rms,
        }
        print(f"[CMR] Vin range within {err_threshold_v*1000:.0f}mV of ideal "
              f"(Aout=Vin): {vin_ok}")
        print(f"[CMR] Within that range: mean err={err_ok_mean*1e6:.1f}uV  "
              f"rms err={err_ok_rms*1e6:.1f}uV")
        print("[CMR] If the error PINS flat at a constant value right at "
              "the edges rather than curving smoothly, that's likely ADC "
              "clipping, not a real DUT limit -- see file header.")
        return self.results["cmr"]

    def run_all(self):
        self.sweep()
        self.save()
        self.plot()
        return self.results
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

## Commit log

2026-07-13 Initial commit: firmware, python, website, pcb structure
    [cmr_opa4388.csv, dc_opa4388_fine.csv, psrr_dc_opa4388.csv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]
2026-09-03 Update website
    [AIMLAB_TESTSTATION_ADC_V1.PRJPCB, AIMLAB_TESTSTATION_ADC_V1.PcbDoc, AIMLAB_TESTSTATION_ADC_V1.PcbLib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]
2026-09-28 License and Cleaning
    [cmr_opa4388.csv, dc_opa4388_fine.csv, psrr_dc_opa4388.csv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]
